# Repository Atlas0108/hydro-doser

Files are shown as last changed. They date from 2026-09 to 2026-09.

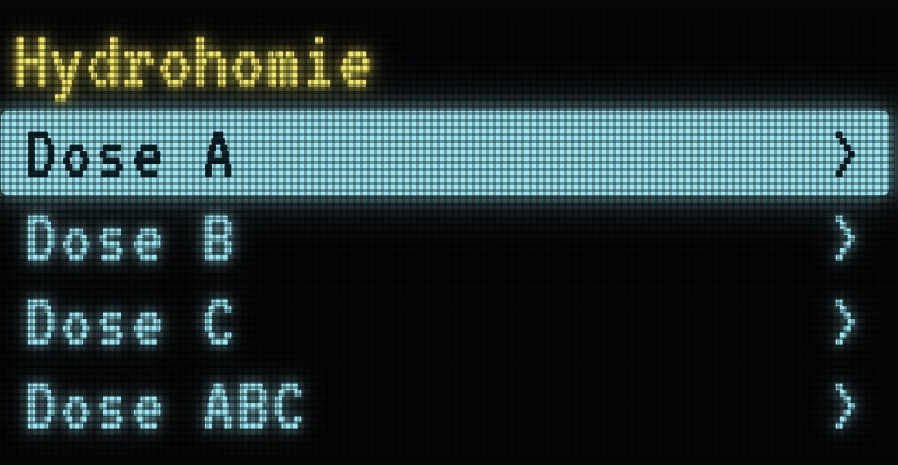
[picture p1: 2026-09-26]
v3/render/screen.jpg

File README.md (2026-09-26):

# Hydro Doser

> **v3 is in [`v3/`](v3/)**: a clean-sheet enclosure on its own feet, a faceplate
> with a screen, a knob and the ESP32, snap-on lid, the pumps across the back.
> Its firmware is in [`firmware/v3/`](firmware/v3/). What follows is v1.

## v3

See [`v3/README.md`](v3/README.md) and [`v3/BRIEF.md`](v3/BRIEF.md).

A low unit that stands beside a hydroponic garden and doses straight into it:
a water tank for top-offs, the Nutrient A and Nutrient B bottles, and three
peristaltic pumps. The firmware is in `firmware/` (still the
earlier four-pump, mix-tank version; it waits until the hardware is
settled).

**Status: printable design, not yet printed.** Seven printed pieces, all
inside the P1S bed, bolted together, no glue, no supports, no special
fittings: the tank is a stock Cambro bin with one hole drilled in its lid.
Layout, fit, joints, tool access and printability are checked by
`verify.sh` (58 checks). Some bought-part sizes are estimates: see *Before
printing*. This version follows an independent review, kept in
`REVIEW-2026-09-23.md`.

```
   ╭──────────╮ ╭───╮       tank: a Cambro 6 qt bin on its dock. Its line
   │  WATER   │ │Spr│       comes out of the column, in through a hole in
   │          │ │   │       the lid, and sits on the bottom
   │          │ │Thr│       column: two cans, one bottle each, front / back
   ├──────────┴─┴───┤
   │ [W]  [S]  ●○○ [T]      base: two trays bolted side by side. Pumps behind
   └────────────────┘       removable covers; one sleeved bundle leaves the
   345 × 225 × 315 mm       back, to the reservoir
```

## Why this shape

- **No mix tank.** A hydroponic reservoir circulates its own water, and the usual
  instruction is to add concentrate to it with each top-off. Dosing
  into the reservoir directly removes a tank, a pump, a manifold, and the
  siphon and stratification problems the review found in the mix tank.
- **Every outlet ends in air.** The three lines run to a printed spout that
  hangs on the reservoir's rim and holds the tube ends above the water.
  Only pickups sit on the bottom (in the tank and the bottles). A primed
  line can't siphon in either direction, and a dose leaves the line after
  every run instead of sitting in it.
- **Nutrient A and Nutrient B never share a line.** Two-part concentrates
  precipitate when they meet undiluted, so each has its own pump, chase,
  and outlet.
- **The tank is a stock Cambro bin with a drilled lid.** Its line comes out
  of the top of its chase, 40 mm above the lid, crosses 30 mm, drops through
  a 10 mm hole and sits on the bottom. To fill: lift the lid, or lift the bin out
  from under its tube. A 3 mm curb on the plate locates it; a 1.5 mm rim
  keeps spills on the plate and a notch at the back drains them off the
  outside of the case.
- **Nothing electrical under the tank.** The ESP32, the ULN2003 and the
  buck sit on standoffs in the column tray, behind the Nutrient B pump.
- **Pumps are serviceable without lifting anything.** Each pump drops into
  its tray from above, motor through a U-slot in a bulkhead, head in the
  front bay behind a 50 mm opening. Its two flange screws are driven from
  the front through that opening; a cover with four countersunk screws
  closes it. The INTLLAB pump's tube nozzles stand off the top of its head,
  so each pump is rolled 42° about its axis: the nozzles point up and
  sideways into the room beside the head, 4.6 mm under the plate, and both
  mounting holes (48.5 mm apart on the flange's axis) land on solid
  bulkhead, clear of the slot. The tubes loop back through a 12 × 28 mm
  slot in the bulkhead.
- **The column is two cans.** The pockets are the walls, so there's no box
  around them, no bridging, and about half the plastic of a boxed column.
  Two walls run from can to can and fuse into both, making the pair one
  box section; the left one carries the tank chase. Three chase tubes, as
  tall as the walls, carry the lines: Nutrient A's and Nutrient B's from the bottle
  caps down through the floor, the tank line up from the floor and out of
  the top. The column's floor
  plate screws down at the three corners the cans leave exposed,
  countersunk, reachable from above.
- **Two trays make the base**, sliced from one rounded body so the seam has
  no groove: three M3 through-bolts (one high, at the middle, so the trays
  can't hinge), three 14 mm tube holes, a wire hole. The bulkhead runs to
  the plate and a second crossbar sits under it, so the 4 mm plate has
  three supports under the tank.

## Pieces

`./export.sh` writes each one into `stl/`, as it prints: standing, no
supports. Masses are solid PETG; the slicer's infill brings the plate and
floors down. Three colours: the trays, plate and the column's floor in matte olive, the
column's towers and the spout in matte white, the sleeves and pump covers in
matte black. For the column, load `stl/two-colour/column_floor.stl` and
`column_towers.stl` together as one object with several parts (Bambu Studio
asks) and give each its filament; they are already in position.

| Piece | Print | Size (mm) | ~g | |
|---|---|---|---|---|
| `tray_dock` | 1 | 225 × 225 × 66 | 580 | tank dock, Water + Nutrient A pumps, panel |
| `tray_col` | 1 | 120 × 225 × 66 | 335 | Nutrient B pump, electronics, jacks |
| `plate` | 1 | 225 × 225 × 7 | 270 | dock plate: curb, drip rim |
| `column` | 1 | 120 × 225 × 249 | 870 | two cans, web walls, three chases; in two colours as `stl/two-colour/column_floor.stl` (green) + `column_towers.stl` (white) |
| `sleeve` | 2 | 95 × 95 × 243 | 180 | for the 125 mL bottles; skip for 1 L |
| `cover` | 3 | 68 × 62 × 2 | 11 | pump covers, 5 mm around each screw |
| `spout` | 1 | 40 × 20 × 42 | 19 | hangs on the reservoir's rim |
| `panel_plate` | 1 | 36 × 48 × 12 | 17 | behind the front wall: two 6 × 6 tactile switches, the LED in its bezel tube |
| `button_cap` | 2 | 14 × 14 × 6 | 1 | through the 12.5 holes, flange behind |

**PETG**, 3 walls, 15 % infill, brim on the big flat pieces. Every piece's
bed contact and unsupported area are measured by `verify.sh` (45° cones
pass, flatter overhangs don't).

Hardware: 9 × M3 heat-set inserts (4 dock posts, 3 column posts, 2 in the
panel plate), 7 × M3×8 countersunk (plate, column), 6 × M3×8 countersunk
(covers), 2 × M3×8 countersunk (panel plate, from the front), 6 × M3
self-tapping (pump flanges), 3 × M3×12 with nuts (seam), M2.5 for the
boards.

**The panel.** Drop the two switches into the plate's pockets (pins out the
back), push the LED in from the back until its flange meets the shoulder,
set the caps in their recesses, offer the plate up behind the wall so the
caps and the LED tube come through, and put in the two screws from the
front. The switch plunger sits 0.1 mm behind the cap; the cap bottoms after
0.4 mm, past the switch's click. Solder the leads on the back afterwards.

## Bill of materials

Everything that isn't printed, with two places to buy each. Roughly
$230 for the parts and $75 for the filament.

| | Qty | Source | Amazon |
|---|---|---|---|
| Cambro CamSquare 6 qt container, translucent (6SFSPP190) | 1 | [WebstaurantStore](https://www.webstaurantstore.com/cambro-6sfspp190-6-qt-translucent-square-food-storage-container-with-winter-rose-colored-gradations/2146SFSPP.html) | [Amazon](https://www.amazon.com/dp/B07FC7L861) |
| Cambro seal lid for the 6 and 8 qt (SFC6SCPP190), drilled Ø10 | 1 | [WebstaurantStore](https://www.webstaurantstore.com/cambro-sfc6scpp190-translucent-6-and-8-qt-camwear-seal-cover/214SFC6SCPP.html) | [Amazon](https://www.amazon.com/dp/B01L7RKD9W) |
| INTLLAB 12 V peristaltic dosing pump, 3 × 5 mm tube (Amazon sells a 4-pack) | 3 | [INTLLAB](https://intllab.net/products/mini-12v-peristaltic-dosing-pump) | [Amazon](https://www.amazon.com/dp/B088TBKNSY) |
| Silicone pump tubing, 3 mm ID × 5 mm OD, about 6 m | 1 | [INTLLAB](https://intllab.net/products/peristaltic-doing-pump-tubing) | [Amazon](https://www.amazon.com/dp/B092V7B77V) |
| ESP32-DevKitC, 38 pin (Amazon's is the WROVER-E variant, same footprint) | 1 | [DigiKey](https://www.digikey.com/en/products/detail/espressif-systems/ESP32-DEVKITC-32E/12091810) | [Amazon](https://www.amazon.com/dp/B087TNPQCV) |
| ULN2003 driver board (six of its seven channels: two per pump) | 1 | [Makerfabs](https://www.makerfabs.com/uln2003-stepper-motor-driver.html) | [Amazon](https://www.amazon.com/dp/B07X2WGK2P) |
| 12 V → 5 V step-down regulator, 2 A or more (Pololu D24V22F5, or any small buck module) | 1 | [Pololu](https://www.pololu.com/product/2858) | [Amazon](https://www.amazon.com/dp/B0GYJDP96Q) |
| 12 V 2 A wall adapter, 5.5 × 2.1 mm plug, UL listed | 1 | [DigiKey](https://www.digikey.com/en/products/detail/cui-inc/SWI25-12-N-P5/7070093) | [Amazon](https://www.amazon.com/dp/B013S9RGNS) |
| Panel-mount DC jack, 5.5 × 2.1 mm, threaded | 1 | [Adafruit](https://www.adafruit.com/product/610) | [Amazon](https://www.amazon.com/dp/B07C46XMPT) |
| Resettable fuse, 1.6 A hold, radial (Bourns MF-R160) | 1 | [DigiKey](https://www.digikey.com/en/products/detail/bourns-inc/MF-R160/259972) | [Amazon](https://www.amazon.com/dp/B0DHSW186L) |
| Vertical float switch, polypropylene, with cable (Cynergy3 RSF54Y100RC) | 1 | [DigiKey](https://www.digikey.com/en/products/detail/sensata-cynergy3/RSF54Y100RC/753328) | [Amazon](https://www.amazon.com/dp/B07DYW1C7P) |
| GX12 6-pin panel connector, socket and plug (float switch, TDS probe, temperature probe) | 1 | [ZYLtech](https://www.zyltech.com/new-zyltech-aviation-plug-6-pin-12mm/) | [Amazon](https://www.amazon.com/dp/B089YT21LY) |
| 6 × 6 × 5 mm tactile switch, 4 pin | 2 | [Adafruit](https://www.adafruit.com/product/367) | [Amazon](https://www.amazon.com/dp/B0796QHL5Z) |
| 5 mm green LED | 1 | [Adafruit](https://www.adafruit.com/product/298) | [Amazon](https://www.amazon.com/dp/B01C3ZZTB4) |
| Push-in grommet for a 5/8" hole, 1/2" ID | 1 | [Grainger](https://www.grainger.com/product/GRAINGER-APPROVED-Grommet-3MPL5) | [Amazon](https://www.amazon.com/dp/B0FH2DNHN6) |
| Expandable braided sleeving, 1/2", 10 ft | 1 | [McMaster-Carr](https://www.mcmaster.com/9284K614/) | [Amazon](https://www.amazon.com/dp/B071ZV6MZ2) |
| M3 brass heat-set inserts (9 used) | 1 pack | [McMaster-Carr](https://www.mcmaster.com/94459A130/) | [Amazon](https://www.amazon.com/dp/B0BVMMBG2N) |
| M3 × 8 flat-head socket screws, stainless (15 used) | 1 pack | [Bolt Depot](https://boltdepot.com/Product-Details?product=7213) | [Amazon](https://www.amazon.com/dp/B01HBN0UU8) |
| M3 × 12 socket-head screws, stainless (3 used, the seam) | 1 pack | [Bolt Depot](https://boltdepot.com/Product-Details?product=6381) | [Amazon](https://www.amazon.com/dp/B01MYX1XBO) |
| M3 hex nuts, stainless (3 used) | 1 pack | [Bolt Depot](https://boltdepot.com/Product-Details?product=4773) | [Amazon](https://www.amazon.com/dp/B01MYX1XBO) |
| M3 × 10 thread-forming screws for plastic (6 used, the pump flanges) | 1 pack | [McMaster-Carr](https://www.mcmaster.com/95893A191/) | [Amazon](https://www.amazon.com/dp/B0779QYZXH) |
| Matte olive green PETG, 1 kg: the trays, plate and column floor | 2 | [California Filament](https://californiafilament.com/products/matte-olive-green-petg-filament-1-75mm-1kg) | [Amazon](https://www.amazon.com/dp/B0GGB1TS3Z) |
| Matte white PETG, 1 kg: the column's towers and the spout | 1 | [eSUN](https://esun3dstore.com/products/petg-matte) | [Amazon](https://www.amazon.com/dp/B0GGBCGJBC) |
| Matte black PETG, 1 kg: the sleeves and pump covers | 1 | [California Filament](https://californiafilament.com/products/matte-black-petg-filament-1-75mm) | [Amazon](https://www.amazon.com/dp/B0GGBMB1HJ) |

## Before printing

1. **Measure a Cambro 6 qt bin and lid**, a small nutrient bottle and a pump, and put
   the numbers in at the top of the `.scad` (`bin_bot`, `bin_r`, `lid_w`,
   `lid_above`, `pump_*`, `b125`). Only the bin's nominal outside size is
   from the spec sheet.
2. **Measure the reservoir's fill opening** for the spout (`rim_t`,
   `rim_drop`).
3. **Print the column tray and one cover first.** They test a pump opening,
   the U-slot, the tube slot, the cover screws, the standoffs and the jacks
   for a few dollars of filament.

**The first dock tray** was printed before the pump drawing arrived, with
the pump axis 2 mm higher (z 34) and pilot holes for a guessed bracket. It
still works: seat each pump at the bottom of its U-slot, roll it 43° so the
nozzles point up and toward the neighbouring pump, mark through the flange's
two holes, and drill Ø2.5. That clears the plate by 2.8 mm. It also has no
holes for the panel plate's screws: drill Ø3.5 at 183 mm from the dock's
left edge, 16 and 52 mm up, and countersink them from the front.

## Files

Published on its own at <https://github.com/Atlas0108/hydro-doser> (this
folder at the root, `firmware/` as `firmware/`); this copy is
the working one.

```sh
./export.sh                                   # every piece into stl/, plus mockup.stl
./verify.sh                                   # 57 checks (export first)
openscad -D 'bottles="1L"' hydro-doser.scad    # the scaled-up bottles
```

`mockup.stl` is the assembled unit with its bought parts, one body, for
viewing only. Open the `.scad` in OpenSCAD to see it in colour.

`verify.sh` checks: the tank clears everything and lifts straight up, the
curb is 3 mm and stops a misplaced tank, the rim is lower than the curb,
the lid hole is over the bin with a straight drop to the floor, the tank
line comes straight out of the top of its chase, 20+ mm above the lid, and the
chases stand as tall as the web walls; 1 L bottles
and the sleeves fit, a 125 mL bottle sits with its cap at the rim, each
chase runs clear top to tray and none opens into a pocket, each web wall fuses into both cans; the pumps sit
inside and lift straight out, the covers fit and their screws meet their
ribs, the flange screws can be driven from the front, each pump's tubes
have a 20 mm loop and pass their slot; the boards rest on standoffs, clear
everything and fit under the column; the panel hardware fits; the seam
carries its holes; the floors are closed; no two printed pieces overlap,
every screw meets its hole, a driver reaches every column and plate screw,
every post stands against a wall, the bulkhead reaches the plate; and every
exported STL fits the P1S, sits on the bed with real contact area, and has
no unsupported overhang.

## Next

- **Firmware** (on hold until the hardware is settled): three pumps, dose
  and top-off straight into the reservoir, the float gate on every run, a water
  tank counter with a refill button, a rolling daily water cap, the panel's
  buttons and light.
- **Level sensing:** a load cell under the dock plate would weigh the tank;
  the plate has the room.
- **Tube ends:** a small weight or a printed foot on each pickup keeps it on
  the bottom.
- **A product version** would mould the two trays as one, the column as one,
  with bosses instead of inserts, a moulded tank and lid, one PCB instead of
  the DevKit and driver boards, and a snap-on pump cover. The layout
  survives.

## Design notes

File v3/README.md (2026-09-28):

# Hydro Doser v3

Detailed to `BRIEF.md`. A printed enclosure on its own feet: three
peristaltic pumps, a screen, a knob and the DevKit on a black faceplate,
the driver and the buck on the side walls, and the two 125 mL nutrient
bottles standing in a deck on the lid. No tank under it.

```
   from the front                          from above, lid off
   ╭───────────────────╮                   ╭───────────────────╮
   │     [=]   (o)     │  bottles 37       │ ═══ ═══ ═══  pumps│  heads forward, rolled 42°,
   │  ▔▔▔▔▔▔▔▔▔▔▔▔▔    │  above the deck   │ ▪   (B)   (A)   ▪ │  motors to the back
   ╰───────────────────╯                   ╰───────────────────╯  ▪ wall boards, (A)(B) cups
    ▪               ▪   feet
   202 x 178 footprint, 85 tall from the plate's underside to the lid, 89 at the deck
```

The lid snaps on; the faceplate is the only screwed piece,
its four screws at the centres of its corner radii. The feet sit at the
centres of the body's corner radii. Every edge is rounded.

Published at <https://github.com/Atlas0108/hydro-doser> under `v3/`, with
the firmware under `firmware/v3/`; this copy is the working one.

## Pieces

| Piece | Prints | Size | |
|---|---|---|---|
| `body` | floor down | 202 × 178 × 82 | floor and walls in one: bulkhead, cups, wall-board ribs, vents, the front opening, the feet's pockets, the rim on top |
| `lid` + `lid_deck` | underside down | 202 × 178 × 11 | flat underneath but for its pocket; the deck on top is the second file, printed black |
| `plate` | face down | 176 × 59 × 28 | black; the screen's pocket, the knob's ribs, and standoffs for the DevKit and the TDS board on its back |
| `knob` + `knob_cap` | base down | Ø36 × 9.5 | the knurled ring brown-red, the cap (face and rounded edge) black; the D bore reaches 1.2 short of the face; the encoder's shaft is cut to 16 above its pcb |
| `ph_adapter` | the bridge's flat back down | 51 × 33 × 18 | no longer used; it clamped the encoder's rib and carried the pH board |
| `foot` | disc down, TPU | Ø18 × 6 | four |
| `spout` | top down, legs up | 40 × 16 × 34 | clips the reservoir's rim |

The lid and the knob each come as two STLs in the same place: the olive (or orange) part and its black part. Load the pair as one object in the slicer (Bambu Studio: import both together and answer yes to loading them as a single object with multiple parts), then give the black part the black filament.

`./export.sh` writes them into `stl/` as they print, no supports. The
front band slopes at 45° underneath; the vents' ceilings, the lid's
pocket ceiling is a short bridge.

Hardware: 4 × M3 heat-set inserts and 4 × M3 × 8 countersunk (the
faceplate), 6 × M3 × 8 (pump flanges, from the motor side, threading into
the flanges' Ø3.2 holes). Bought parts as in `BRIEF.md`.

## How it goes together

- **Body.** Floor and walls in one piece, open at the top. The floor is
  4 thick with a 1.5 chamfer under its edge, the one edge that is not
  rounded, because it prints from the bed. Four TPU feet snap into the
  floor at the corners' radius centres, a disc in a pocket underneath and
  a lipped peg into a counterbore above, flush with the floor's top.
- **Pumps.** Three INTLLAB pumps lie across the back, heads forward,
  motors through U-slots in a bulkhead at 125 and back to the wall, all
  standing on the floor. Each
  is rolled 42° about its axis, as in the first design, so its diamond
  flange's two holes sit on a 42° line: one high on the right, one low on
  the left of the axis. The bulkhead has Ø3.4 holes to match; the screws
  go in from the motor side, between the motors with a stubby or
  right-angle driver, and thread into the flange. Nozzles lean left. Pump
  0 (right) is Nutrient A, pump 1 (middle) Water, pump 2 (left) Nutrient
  B.
- **Cups.** Two Ø52 tubes (2 mm round the Ø48 bottles) side by side in the middle of the front, open
  at both ends. A bottle stands on the base plate and shows 37 above the
  deck. Two Ø8 holes through the lid, their mouths rounded, one 16 out
  from each bottle on its outer side for the nutrient tube. The water
  tube comes in through a plain Ø8 hole high in the back wall, above
  the middle motor, and runs forward over the motor and the bulkhead to
  the nozzles.
- **Bottles.** The Rise Gardens 125 mL Sprout and Thrive bottles, measured
  Ø48 × 122: a white HDPE cylinder round, rounded shoulder, 24 mm neck, a
  black disc-top cap, a wraparound label (Sprout green, Thrive blue). In the
  model as body, cap and label so the pages and the render colour them apart.
- **Wall boards.** The ULN2003 stands in two slotted ribs on the right
  wall and the buck in two on the left, beside the cups, dropped in from
  above with the lid off; the boards rest on the slots' floors just off
  the body's floor, components inward.
- **Vents.** Seven rounded slots, 40 × 2, in each side wall beside the
  motors, at 5 mm pitch from 12 up.
- **Faceplate.** A black plate, 3 thick, 96 × 59, centred on the front
  and flush with it, its edge and the opening's edge rounded 1 so the
  seam is a soft groove. Four M3 × 8 at its corner-radius centres into
  inserts in a 12 mm band behind the wall. On its back: the OLED drops
  straight into a pocket, a 3 mm frame 0.3 clear each side and 0.2 top
  and bottom, its glass in a blind recess behind the face (a dab of hot
  glue or foam tape keeps it seated); the window
  the size of its picture; the KY-040 sits between two ribs, its nut on
  the floor of a Ø38 × 2 recess, and the Ø36 knob hides the nut in a
  pocket in its base, sits 0.5 off the recess floor, and stops on the
  shaft's end (the KY-040's 20 mm shaft cut to 16 above the pcb; the
  knob is 9.5 thick and its D bore runs to 1.2 short of the face).
  The screen sits dead centre; the knob is midway between the screen's
  centre and the plate's right edge. Left of the screen, as seen from
  the front, the 30-pin ESP32 DevKit lies along the plate, its left end
  4 short of the left screws' inserts. It stands on four Ø5.5 standoffs, 5 tall, module toward the plate and
  pins pointing into the box, held by M2.5 self-tappers through its
  corner holes into Ø2.2 pilots. The holes are taken as Ø3, 2.3 in from
  each edge (46.9 × 23.7 apart): measure your board and change
  `esp_hole` if it differs. The band behind the wall is notched there
  so the board clears it, the notch's ceiling sloped 45° so it prints.
  Straight behind the screen, the DFRobot Gravity TDS (or pH V2) signal
  board, 42 × 32, lies along the plate on four Ø6 standoffs, 25 tall, so
  it clears the screen's header and the Dupont plugs on it; its back
  runs between the two cups. Two of the standoffs merge into the
  screen's side ribs. M3 self-tappers through its corner holes into
  Ø2.6 pilots. The holes are taken as Ø3.1, 3.5 in from each edge (35 ×
  25 apart): measure your board and change `tds_hole` if it differs.
  Fit the screen before the board: the board covers its way in.
  The knob's encoder is fitted with its pins out of its short edge,
  toward the plate's right edge, so only one rib stands beside it (the
  one toward the screen); its harness leaves past the open side. It
  stands 14 off the plate's back. (No longer used: the pH probe now
  keeps its own cable through the back wall, and the pH board is off the
  faceplate. Skip printing `ph_adapter`.) The pH board (PH-4502C type, 42 × 32)
  hung on that rib on a printed adapter, `ph_adapter`:
  a leg on the rib's outer face, a lip over its top, and a tab on its
  inner face above the encoder's board clamp it both ways; a bridge 1.5
  behind the encoder reaches across the harness side and carries the
  board flat on its back, toward the harness side so its parts clear
  the right cup, and rests on a second full-height leg at its far end,
  windowed for the harness. M3 self-tappers into Ø2.6 holes through the
  bridge. The holes are
  taken as Ø3.1, 3.5 in from each edge (35 × 25 apart): measure yours
  and change `phb_hole` if it differs.
  Fit all four, then screw the plate on.
  The window sits 14 from the plate's edge, the same as the knob's
  recess; the screen's outer rib lands where the band would be, so the
  band is notched there between the two screws.
- **Back.** The jack, the pH cable's hole and the GX12-6 on one line
  low in the back wall, 11 up from the floor's top: the jack and the
  GX12 between the motors, the pH hole (Ø16) under the middle motor.
  The pH probe keeps its stock cable: its BNC plug (about 14.5 across)
  passes through, and a grommet goes back round the cable. Above the
  middle motor, 48 up, three Ø6.4 holes 13 apart take the outlets'
  uxcell M6 bulkhead barbs (B0F5X3DXQ5): 3 mm barb outside for the
  hoses, nut and 4 mm barb inside for the doser's tubes. They sit right
  of centre so a driver still reaches the middle pump's upper screw.
  The nutrient tubes run back over the bulkhead and down to them. The
  water tube's hole is above them, 58 up.
- **Lid.** Flush with the walls, 7 thick with a 4 mm round on its edge.
  A 1.5 mm rim rises 4 from the walls' inner half with a ridge round its
  inside; the lid's underside has a pocket ring over it with a groove the
  ridge clicks into, so nothing hangs below the lid and it prints flat.
  A raised deck over the cups, rounded on top with a cove at its foot.

## Texture

The body's vertical faces get a fuzzy-skin band, from 4 above the bottom
up to the lid seam, so it clears the faceplate by the same 3.3 above and
below, stopping 3 mm short of the faceplate's
opening. The faceplate, lid and base stay smooth. It is a slicer effect,
so nothing in the STL changes; `stl/fuzz-modifier.stl` is a modifier
shell that puts it exactly there:

1. In Bambu Studio or OrcaSlicer, select the body, right-click, Add
   Modifier, Load, pick `fuzz-modifier.stl`. It lands in place (same
   origin as `body.stl`).
2. On the modifier, set Fuzzy Skin to Contour, thickness 0.3, point
   distance 0.8. In OrcaSlicer 2.3 or later pick a noise type: Perlin at
   feature size 1 for a fine grain, Voronoi at 2 to 3 for a patchwork.
3. Leave Fuzzy Skin off on the body itself and every other piece.

Contour fuzzes only the outer wall, and only inside the shell, so the
snap fits, the opening and the cavity stay smooth. Print a small test
band first: fuzzy skin adds 0.3 to the outside, so the lid and base seams
show a 0.3 step unless the texture band is what you want to read there.
(The body's bottom 4 mm and the lid sit inside the band.)

## Checks

`./verify.sh` (export first) runs the boolean checks: the floor closed;
feet at the radius centres, snapping in and staying under; the
lid on the shoulder, its pocket over the rim, snapping, located, flush,
flat underneath; bottles dropping in and showing 30; tubes up through
their three holes; pumps seated, lifting out, their flange screws on the
42° line reaching from the back with a driver; tube runs to the holes
and the grommet; the DevKit on its standoffs, the wall boards in their
slots, all sliding in, held and clear; ports between the motors; vents
open; the plate seated on its band, flush, held every way, its screws
at its radius centres, the seam groove open; the encoder, nut, knob and
D flat; the screen sliding in, held, its picture shown; the spout; every
piece on the bed, unsupported and manifold.

## Open

- The bottles measure Ø48; their height, 122, is still an estimate.
- Firmware: v1's pin plan with the pumps re-labelled (0 A, 1 Water, 2 B),
  the OLED on GPIO21/22, the encoder on 18/19/23.
- The float switch has no mount yet.

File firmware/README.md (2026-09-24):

# Hydro Doser → mixes nutrient water and tops off the garden

An ESP32 running ESPHome (`hydro-doser.yaml`), with four 12 V peristaltic
pumps (INTLLAB 4-pack) switched by two ULN2003 boards.

**Status: firmware written and compiling. Hardware not built yet.**

```
 Nutrient A bottle ──[Nutrient A]──┐
 Nutrient B bottle ──[Nutrient B]──┤
 water jug     ──[Water]───┴──►  mix tank  ──[Transfer]──►  reservoir
                                                              (float switch)
```

The reservoir only ever gets something from the mix tank: plain water
(*Mix Water Batch*) or nutrient water (*Mix Nutrient Batch*). Nutrient never
goes straight into the garden, and Nutrient A and Nutrient B never touch each other
undiluted.

## Parts

| | |
|---|---|
| ESP32 dev board | any ESP32-WROOM DevKit (`board: esp32dev`) |
| 4 × peristaltic pump | INTLLAB 12 V DC, 5–100 mL/min. The motor must stay dry: mount the pumps above the tanks. |
| 2 × ULN2003 board | the ones from the stepper kits, jumper set to 5–12 V |
| 12 V supply | 12 V, 2 A or more |
| 12 V → 5 V buck | powers the ESP32 from the same supply |
| Float switch | in the reservoir, at the fill line |
| Mix tank | anything with a lid. Set *Mix Tank Capacity* to match. |
| Silicone tubing | to fit the pump barbs, plus spares: pump tubing wears out |

## Wiring

| ESP32 | goes to | |
|---|---|---|
| GPIO25 | board A IN1 **and** IN2 | Nutrient A |
| GPIO26 | board A IN3 **and** IN4 | Nutrient B |
| GPIO27 | board B IN1 **and** IN2 | Water |
| GPIO32 | board B IN3 **and** IN4 | Transfer |
| GPIO33 | float switch → GND | reservoir full |
| GND | both boards' −, buck −, 12 V − | **common ground, required** |
| VIN (5V) | buck 5 V out | |

Each pump uses two channels in parallel, so there's plenty of current margin.
On each board, the pump's **+** goes to the board's **+** pin (12 V). Its
**−** goes to both OUT pins on the white connector for its two channels.
The ULN2003 has flyback diodes built in. If the ESP32 resets when a pump
starts, solder a 100 nF capacitor across that motor's terminals.

**The float switch has to be fail-safe.** Mount it so the contact is **closed
while the water is below it**. Most float switches flip over to change which
way they work. An open circuit reads *full*: an unplugged or broken switch
blocks transfers rather than letting the pump run until the reservoir
overflows. With no float wired, *Transfer to Reservoir* does nothing, by design.

## Calibrate before first use

The pumps are rated "up to 100 mL/min". The real rate depends on the tubing
and on the ~1 V the ULN2003 drops, so measure it:

1. Put the pump's inlet in its liquid and its outlet in a measuring cup.
2. Choose it in *Calibrate Pump*, then press *Run Pump 60 s*. The first run
   also primes the tube, so empty the cup and run it a second time.
3. Enter the mL it moved as that pump's *Flow* (mL/min).

Recalibrate every few months. As the tubing wears, the flow drops.

## Use

1. Set **Nutrient A Dose** and **Nutrient B Dose** (mL per liter of water) from the nutrient maker's
   feeding directions. Both start at 0. Set Nutrient A back to 0 once the plants
   no longer need it.
2. **Mix Nutrient Batch** or **Mix Water Batch** fills the mix tank with
   *Batch Size* liters: 80% of the water, then Nutrient A, then Nutrient B, then the
   last 20% of the water to rinse the lines and stir the tank. The whole batch
   is checked first: if it won't fit in the tank or needs too long a run, it
   doesn't start.
3. **Transfer to Reservoir** pumps up to *Transfer Amount* liters (0 means all of
   it) into the garden. It stops early if the float trips or the mix tank
   runs out.
4. **Stop** stops everything. A run that was cut short still counts toward the
   mix tank.

**Status** shows the last thing the doser did or refused. **Nutrient A Used** and
**Nutrient B Used** count up from the last *Bottle Refilled* press.

The same things are available as HA actions, for automations:
`esphome.hydro_doser_dose` (`pump`: sprout/thrive/water/transfer, `ml`),
`esphome.hydro_doser_make_batch` (`liters`, `nutrients`),
`esphome.hydro_doser_transfer` (`liters`, 0 = all).

## How it keeps count, and its limits

Nothing measures the mix tank. **Mix Tank Volume** is flow rate × run time,
kept across reboots. If it drifts (spills, hand-filling, a bad calibration),
empty the tank and press *Mix Tank Emptied*.

- Only one pump runs at a time. Commands wait in a queue.
- A single run is capped at 45 min (4.5 L at 100 mL/min). A fill needing more
  than that is refused; a transfer stops at the cap and leaves the rest.
- A dry water jug isn't detected. Peristaltic pumps survive running dry, but
  the count will then overstate what's in the tank.
- At ~100 mL/min, a 2 L batch takes about 20 min, and so does the transfer.

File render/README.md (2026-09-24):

# Renders and pages

Source for the exploded-view page, the product page and the Blender
explosion. Frames, part STLs for the viewer and the MP4 are outputs and are
not kept here; regenerate them.

| File | What |
|---|---|
| `doser.py` | Blender 5.2 scene: imports the part STLs (each bought part as its own pieces), matte olive PETG, a dark studio, animated screws, and renders the explosion as a 96-frame WebP sequence plus a hero still. `--device CPU\|METAL\|HIP`, `--test` renders four check frames. |
| `encode.py` | Blender's FFmpeg: frames → MP4, forward, hold, reverse, hold. |
| `viewer.html` | The interactive exploded view (three.js). Expects `parts/<name>.txt`: base64 binary STLs, one per part instance. |
| `product.html` | The product page. Expects `frames/f001..f096.webp` and `frames/hero.webp`. |

```sh
# part STLs for the viewer / Blender, one per instance (see the scad's output section)
openscad -o parts/column.stl --export-format=binstl -D 'part="piece"' -D 'idx=3' ../hydro-doser.scad
# full render on node-01 (32-thread CPU, ~40 s a frame at 64 samples)
blender -b -P doser.py -- --device CPU --frames 96 --samples 64 --parts parts --out frames
blender -b -P encode.py -- frames hydro-doser-explosion.mp4
```

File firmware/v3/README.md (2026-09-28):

# Hydro Doser v3 firmware

ESPHome on an ESP32 DevKitC. A 0.96" OLED and a KY-040 knob on the
faceplate drive a menu, so it works without a phone: turn to choose, click
to open, click to run, turn up past the top to go back. Three 12 V peristaltic pumps
through a ULN2003. Home Assistant sees it as a device with three pump
switches, a Cancel button, a Status text, a flow-rate number per pump, and
`dose` and `cancel` actions. Whatever Home Assistant starts shows on the
screen the same as a knob-started run: the countdown and the cancel
button, or the manual page with a stop button.

## Setting it up

Nothing is baked in: no network, no password, no key. Plug it in and
set it up on a network. Two ways,
both local:

1. Open the Home Assistant app on a phone near it, with Bluetooth
   allowed. It finds "hydro-doser-v3" over Bluetooth (Improv) and asks
   for the Wi-Fi network and password. Any Improv client works the same
   way; the unit here was set up from a Mac with a 40-line Python script.
2. Or join the open Wi-Fi network "Hydrohomie" the doser raises; a page
   pops up to enter the network and password.

Once it is on the network it remembers it, and Home Assistant lists it
under Discovered on the integrations page; click Add. No key to paste.
If Home Assistant runs in Docker on a Mac with port mapping, as on the
iMac here, it cannot see mDNS and will not discover anything: add the
ESPHome integration by hand with the host `hydro-doser-v3.local` (or its
address) and port 6053. To make a unit forget its network, erase the
`nvs` partition (`esptool erase_region 0x390000 0x70000`) or hold no
network: the set-up modes come back.

A dose's time is ml divided by the pump's flow rate. The rates default to
100 mL/min; calibrate each pump (run 50 ml into a measuring cup, adjust
the number in Home Assistant) before trusting the quantities.

## Wiring

Everything on the faceplate's back. The OLED's four pins face into the
box; the knob's five pins point down.

| From | To ESP32 | Notes |
|---|---|---|
| OLED GND | GND | |
| OLED VCC | 3V3 | the 0.96" SSD1306 boards run on 3.3 V |
| OLED SCL | GPIO22 | I2C clock |
| OLED SDA | GPIO21 | I2C data |
| Knob CLK | GPIO19 (D19) | encoder |
| Knob DT | GPIO18 (D18) | encoder |
| Knob SW | GPIO5 (D5) | the push button, pulled up in firmware |
| Knob + | GPIO17 (TX2) | driven high at boot: its 3.3 V |
| Knob GND | GPIO16 (RX2) | driven low: its ground |

The knob's five pins, CLK, DT, SW, + and GND, land on D19, D18, D5, TX2
and RX2, which sit side by side on the DevKit V1's header, so its plug
goes on in one piece with CLK on D19. The two pins at the end power it;
it draws about 1 mA. If it turns the wrong way, swap `pin_a` and
`pin_b` in the yaml. The OLED's address is 0x3C; if the screen stays dark
and the log says no device at 0x3C, it is the 0x3D kind: change `address`.

Pumps, through the ULN2003 (its + and its jumper as in the first
design). The menu's A, B, C are Nutrient A, Nutrient B, Water:

| From | To ESP32 | Menu |
|---|---|---|
| ULN2003 IN1 | GPIO25 | A, Nutrient A, the right pump |
| ULN2003 IN2 | GPIO26 | C, Water, the middle pump |
| ULN2003 IN3 | GPIO27 | B, Nutrient B, the left pump |
| ULN2003 - | GND | |

The Gravity TDS (or pH V2) signal board, on its 3-pin plug. Its supply
comes from GPIO13, so the firmware can switch the board off while pH
reads (it draws a few mA). GPIO35 is on ADC1, which reads with Wi-Fi
on.

GPIO32, the board's first supply pin, was damaged on 2026-09-28. The +
and - wires moved to D13 and the GND pin beside 3V3, and GPIO32 and GPIO33
are left unused. Before powering the board from a new pin, check its +
and - aren't shorted together (unplugged, the meter should read well
over 1 kΩ between them), or the new pin goes the same way.

| TDS board | To ESP32 | Notes |
|---|---|---|
| A (signal) | GPIO35 | analog in, 0 to 2.3 V |
| + | GPIO13 | driven high at boot: 3.3 V |
| - | GND | the GND pin beside 3V3, bottom of the other side |

On the 30-pin DevKit V1, D13 is near the bottom of the VN-side header
(... D14, D12, **D13**, GND, VIN) and the A wire goes to D35 higher up
the same side. The - wire goes to the GND pin at the bottom of the
other side, beside 3V3: the GND beside D13 left the board unlit when
tried on 2026-09-28.

The pH board (the common PH-4502C type, 42 × 32, the one sold with a BNC
probe) needs 5 V, and its Po output reaches about 5 V at the acid end:
too much for an ESP32 input. So Po goes through a divider, 10 kΩ from Po
to GPIO34 and 20 kΩ from GPIO34 to ground, which scales 5 V to 3.3 V;
the firmware multiplies back by 1.5.

| pH board | To | Notes |
|---|---|---|
| Po | 10 kΩ, then GPIO34 | 20 kΩ from GPIO34 to GND |
| V+ | 5 V (VIN, or the buck's OUT+) | |
| G | GND | either G |
| Do, To | — | unused |

The float switch goes between GPIO14 and GND; the firmware pulls GPIO14
up. **Mount it so its contact is closed while the water is up at the
float** (flip the float on its stem to change which way it works). Then
an open contact, from low water or a broken or unplugged lead, reads
**Reservoir low**, so dosing can be blocked on it safely.

The TDS probe and the float come in through the GX12-6 in the back
wall. Cut the TDS probe's plug off and wire the board's probe input to
the GX12 socket instead:

| GX12 pin | Wire | Goes to |
|---|---|---|
| 1 | green | float switch: GPIO14 (D14) |
| 2 | yellow | TDS board's probe input (either way round with pin 4) |
| 3 | white | spare |
| 4 | blue | TDS board's probe input |
| 5 | no wire | unused |
| 6 | black | float switch: GND |

Pin numbers are as seen on the connector's front (mating face), key at
the top: pin 1 at the bottom right, 2 to 5 running anticlockwise round
the ring, 6 in the centre. The map follows the wiring as built
(2026-09-27): pin 5 has no wire. The TDS probe is on yellow and blue (2 and 4),
the float on green and black (1 and 6). The float switch has no
polarity; black takes ground by convention.

The pH probe keeps its stock cable, uncut. It comes in through its own
hole in the back wall, beside the GX12, and its BNC plugs straight into
the pH board. The pH board is no longer on the faceplate; keep it and
the cable away from the pump wires, since the probe's signal is very
high impedance.

The probes share the reservoir, and the TDS board's excitation current
upsets the pH probe. So the doser reads them in turn, every 30 s: TDS
first, then it switches the TDS board off (it is powered from two GPIOs
for exactly this), waits 3 s, reads pH, and switches the TDS board back
on to settle before its next reading. Both readings update every 30 s.

pH is two-point calibrated. Put the probe in pH 7 buffer and press
**Calibrate pH 7**; rinse it, put it in pH 4 buffer and press
**Calibrate pH 4**; each button takes a fresh reading, with the TDS
board off, before it saves. The two settings, pH 7 voltage and pH slope, can
also be set by hand.

Home Assistant gets TDS in ppm, the raw TDS voltage (diagnostic), and
two settings: Water temperature, which the reading is compensated to
25 °C with (there is no temperature probe yet, so set it), and TDS
calibration, a factor to trim the reading against a known solution.
The conversion is DFRobot's: the voltage over 1 + 0.02 × (T - 25), then
(133.42 v³ - 255.86 v² + 857.39 v) × 0.5 × the factor.

**Nutrient level** reads Low, Nominal or High against a reading marked
as nominal: the Rise reservoir dosed to spec read 592 ppm on
2026-09-26, and that is the default. It goes Low below nominal minus
the **TDS band** (10 % by default) and High above nominal plus it, with
2 % of hysteresis so it doesn't flicker at the edge. After a fresh fill
dosed to spec, press **Mark TDS nominal** to take the current reading
as the new nominal. When the probe reads 0 (dry or unplugged) the level
is "No reading", so an auto-doser built on it never doses on a dead
probe.

## Flashing

```sh
esphome run hydro-doser-v3.yaml --device /dev/cu.usbserial-110    # over USB (the CH340 port on this Mac)
esphome run hydro-doser-v3.yaml --device hydro-doser-v3.local     # over the air after that
esphome logs hydro-doser-v3.yaml --device /dev/cu.usbserial-110   # watch it
```

There is no `secrets.yaml`: the firmware has no secrets.

## In a dashboard

`dashboard-section.yaml` is a ready-made section for a Home Assistant
sections dashboard: Status, Cancel, the dose buttons at 5, 10, 25 and
50 ml for A, B, C and ABC, the manual pump switches and the flow rates.

## The menu

Home lists Dose A, Dose B, Dose C, Dose ABC and Settings.

```
  Hydrohomie  click ->   Dose A        click ->   Dose A, 25 ml
  > Dose A               > 5 ml                   12 s left
    B                      10 ml                  click to cancel
    C                      25 ml
    ABC                    50 ml
                           Manual       hold ->   A running
                                                  release to stop
```

Settings holds PIN, Autolock and Reset. PIN sets a four-digit PIN: turn
to pick each digit, click to move on; 0000 clears it. Autolock (Off,
1 min, 5 min) locks the screen after that long without a touch, and needs
a PIN first: chosen without one it says "Set a PIN first". A locked
screen asks for the PIN before the menu is usable; Home Assistant is not
affected. Reset, after a confirmation, forgets the network, the PIN and
the settings and reboots into set-up.

Turn: move the highlight. Click: open the dose, then run the quantity,
and while it runs, click again to cancel; a run started from Home
Assistant shows the same pages and a click stops it too. To go
back from any menu, turn up past the first item to highlight the title
band as Go back and click it; on PIN entry, turn back past 0 on the
first digit. Holding the button never goes back. On Manual, the pump
runs from the moment the button goes down until it is released; on
ABC's Manual all three run together. On the home screen, a 3 s hold
turns the screen off; a click turns it back on and does nothing else,
and the knob does nothing while it is off. The doser keeps working with
the screen off, and a dose started from Home Assistant turns it back on
to show the countdown, then off again when the run ends or is cancelled
(unless the knob was touched meanwhile). A hold anywhere else does nothing. A timed ABC runs A,
then B, then C, each for the chosen quantity.

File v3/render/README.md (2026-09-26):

# Render

The Blender explosion of v3. Frames, the part STLs and the MP4 are
outputs and are not kept here; regenerate them.

| File | What |
|---|---|
| `doser-v3.py` | Blender 5.2 scene: imports the parts exported in assembly position, matte olive PETG, a black plate, the brown-red knob, a dark studio, and renders a basic explosion (every part slides straight out, together, the wall boards staying put) as a 96-frame WebP sequence plus a hero still. `--device CPU\|METAL\|HIP`, `--test` renders three check frames. |
| `routes.py` | The tubes and the faceplate's heat-set inserts as routes in model mm, each point riding with the part it is attached to; `python3 routes.py > routes.json`. The scene and the exploded-view page both read `routes.json`. |
| `encode.py` | Blender's FFmpeg: frames to MP4, forward, hold, reverse, hold, 24 fps. |

```sh
# the parts, one STL each in assembly position
for p in body_at:body lid_at:lid deck:deck plate_at:plate knob_at:knob cap:cap feet:feet screws:screws encoder:encoder oled:oled ports:ports; do
  openscad -o parts/${p#*:}.stl --export-format binstl -D "part=\"${p%:*}\"" ../hydro-doser-v3.scad; done
for i in 0 1 2; do for p in pump board; do openscad -o parts/$p$i.stl --export-format binstl -D "part=\"$p\"" -D "idx=$i" ../hydro-doser-v3.scad; done; done
for i in 0 1; do openscad -o parts/bottle$i.stl --export-format binstl -D 'part="bottle"' -D "idx=$i" ../hydro-doser-v3.scad; done
# on node-01 (32 threads): a preview at about 8 s a frame, the high-quality pass at about a minute a frame
python3 routes.py > parts/routes.json
blender -b -P doser-v3.py -- --device CPU --frames 96 --samples 64 --parts parts --out frames
blender -b -P doser-v3.py -- --device CPU --frames 120 --samples 192 --width 2400 --parts parts --out frames
blender -b -P encode.py -- frames hydro-doser-v3-explosion.mp4
```

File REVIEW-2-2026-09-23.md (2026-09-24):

# Rise Doser review 2 (2026-09-23, post-rebuild)

Second independent review, of the one-tank three-pump rebuild, by a reviewer
with no part in the design and the first review in hand. Kept here because
the next round of changes is driven by it. Nothing in it has been acted on
yet.

Files: `rise-doser.scad`, `README.md`, `verify.sh`, `REVIEW-2026-09-23.md`,
`stl/*`. The reviewer ran `verify.sh` (51/51 pass), rendered the assembly
and each piece, ran 25 extra boolean probes and a per-z-band overhang
analysis.

## Previous review: what was actually resolved

Resolved: column prints on its floor (bed 26,606 mm², 65 mm² unsupported);
rails gone; column screws countersunk, outside the cans, driver-reachable;
bulkhead to 65.5 + crossbar under the plate; 3 mm curb; 10×10 posts; third
seam bolt at z=56; bottom fillet 1.5; floor slots gone; tee gone, separate
Sprout/Thrive lines; exit 45 mm above the lid (was 8.7); barb-to-slot bend
~22 mm (was 9); electronics out from under the tank; pumps front-serviceable;
standoffs exist; wire hole; button pitch 24; mix tank dropped; polyfuse in
BOM; brim documented.

**Not resolved or mis-resolved:** (a) the siphon blocker was fixed only in
the reverse direction (see §3); (b) mass target <1.5 kg: still 2,516 g solid
(`verify.sh` sum); (c) USB reach got worse (16 mm, was 6); (d) standoffs have
no screw holes; (e) round holes still not teardropped (the helper was
deleted); (f) sleeve/pocket fit 0.75 mm radial (asked ≥1); (g) bolt
heads/nuts still unmodelled; (h) tube routes still tested as stubs/boxes,
not paths; (i) no prime/flush/panel firmware (on hold, fine, but the
hardware now needs: 3 pump outputs, 2 button inputs, 1 LED, float input,
per-line prime volume, calibration, daily cap, tank counter).

## 1. Mechanical

- **Should fix — dock plate 0.5 mm off its supports.** `bulk_h = tray_h -
  0.5`: bulkhead and crossbar top out at 65.5, plate underside at 66. The
  plate must sag 0.5 mm before "three supports" exist. Strip estimate for
  the 125 mm bay (y 40→165) under ~6.3 kg (5.7 L + ~0.6 kg bin/lid): 0.46 mm
  solid, ~0.8 mm at 15 % infill, then PETG creep. Set the gap to 0.2 or make
  the plate 5–6 mm; the walls, bulkhead and crossbar print in the same layers
  so they are coplanar anyway.
- **Should fix — curb clearance is 1 mm on an estimated dimension.**
  `rsq(bin_bot + 2, …, bin_r + 1)`. The real CamSquare base is a stacking
  recess whose size and corner radius haven't been measured; PETG shrink on a
  197 mm bore is ~0.6–1 mm on its own. Use bin_bot + 5 and a generous inner
  corner radius. The 6 mm-offset self-test still passes against a
  sharp-cornered modelled bin.
- **Should fix — cover is taller than the tray.** `cover_w = 66` centred on
  `pump_z = 34` spans z 1…67; the tray is 66 tall. Probe: 310 mm³ of cover
  above z=66 (in front of the plate/column-floor line) and 137 mm³ below
  z=1.5 (over the bottom fillet). The three surface-mounted 2 mm plates cut
  across the plate seam by 1 mm and hang at the fillet. Make the cover ≤62
  tall (z 3…65) or recess it 2 mm into the wall so it sits flush.
- **Should fix — cover screw count is inconsistent.** Model drills 4 holes
  per cover; README and scad comment say "two"; BOM says "6 × M3×8". Model =
  12 screws. Also: M3 machine screws self-tapped into 2.8 mm PETG holes,
  removed at every tube change, will strip; the ribs (8 wide) are too thin
  for inserts — make them 10 wide with 4 mm insert holes, or use 2 screws +
  a hooked lower edge.
- **Consider — pump hangs on two 3 mm-deep self-taps.** Lower pair only,
  into a 3 mm bulkhead (2.5 threads). All four flange holes are reachable
  through the opening (the corners' r=4 arcs are centred on them); use all
  four, or M3 with nuts behind (reachable from above with the plate off).
- **Consider — no fillet on any can top, chase top, the collar's four
  vertical edges, the spout, or the sleeve.** Probe: the front can's outer
  top 1 mm × 1 mm ring is 100 % material. The can rims at z=315 are exactly
  where hands go for bottle changes; the chase tops chafe the tubes. The
  owner's rounding rule is not met and `verify.sh` doesn't check it.
- **Consider — the collar is a solid 30 × 17 × 249 mm block**: ~100 cm³,
  ~126 g, doing the job of a 4 mm shell around a 16 mm chase.
- OK: walls 3, floors 4, posts 10×10/Ø4 (3 mm walls), every post against a
  wall (verified), 4 mm insert holes (spec 4.0–4.2; after PETG shrink ~3.8,
  expect to ream).

## 2. Printability (P1S, no supports, as exported)

- **Blocker — the sleeve's rim ring floats.** The 6 mm ring at z 237…243
  (r 44.5…47.25) sits 15 mm outside the cup (r 29.75) and touches only three
  2 mm fins. 512 mm² of flat down-facing area at z≈237 — a curved 2.75
  mm-wide "bridge" of three ~80 mm arcs with nothing under them. Curved
  bridges don't bridge; the ring will droop into spaghetti. `verify.sh`
  passes it because its threshold is a total of 800 mm². Fix: carry the ring
  on a 45° conical skirt from the cup wall, or delete the ring (the fins
  already locate at r=47.25) and put a lift tab on one fin.
- Should fix — sleeve fins are 2 mm × 243 mm; from z 4…83 the part is three
  free 2 mm blades joined at the axis. Prints, but flimsy/twisty; 3 mm or
  four fins.
- Consider — 42 mm flat bridges over each pump opening: the P1S will bridge
  3 mm-deep spans, but they'll sag 0.3–0.5 mm behind the cover. Arch or
  chamfer the top of the opening; same for the Ø16 grommet hole. The
  teardrop helper was removed rather than used.
- Consider — PETG shrink on hardware holes: light pipe Ø8 in Ø8 (24 mm³
  interference at a 7.6 printed hole), GX12 Ø12.2 for a 12 mm thread,
  buttons Ø12.5. Add 0.4 to every panel hole.
- Consider — sleeve OD 94.5 in a 96 pocket (0.75 radial) on a 243 mm-deep
  press: PETG-on-PETG friction, no draft. Use 1 mm and a draft on the pocket
  or three contact ribs.
- Cover exports correctly (fillet and countersinks up, 0 mm² unsupported);
  the scad comment "outside face on the bed" is wrong.
- Warp: 225 × 225 tray and plate in PETG — brim is documented; fine on the
  textured plate.

## 3. Plumbing

- **Should fix (top of list) — forward siphon is still only held by roller
  occlusion, and the README claims otherwise.** README: "A primed line can't
  siphon in either direction." An outlet ending in air only stops Rise→doser
  backflow. A siphon runs whenever the *source* surface is above the
  *outlet* and the line is full; the peak height is irrelevant. Sources
  here: tank surface up to z≈250, a 125 mL bottle's liquid to z≈310, a 1 L
  bottle's to z≈300–315 — the highest liquids in the unit — against a spout
  at the Rise rim, which for every Rise model is well under 300 mm above the
  doser's floor. A worn pump tube (months) siphons up to 1 L of concentrate
  or 5.7 L of water into the Rise with no float, firmware or valve in the
  path. Cheap fix with no valves: run each outlet line up its own chase to a
  vented tee at the column top (above z=315), then down to the bundle — an
  anti-siphon loop; the column already has the chases. Or accept it
  explicitly and say so in the README instead of the opposite.
- **Should fix — the tank line's side exit kinks the tube.** Chase bore Ø12,
  exit hole Ø10 at z=301, open top at 315. A 6.35 tube turning 90° inside a
  12 mm bore into a 10 mm hole has a centreline radius of ~8 mm; 1/4"
  silicone kinks below ~15–20. Cut the exit as a slot from z=301 to the top
  with a rounded lip, or slope it 45° down.
- **Should fix — the bundle doesn't fit its grommet.** Three Ø6.35 tubes
  circumscribe 13.7 mm; with a 3 mm float lead ~15; braided sleeve ~16–18
  mm. The model draws an 11 mm bore in a 16 mm hole. Needs a ~22 mm panel
  hole with a ≥16 mm bore, or a split grommet.
- **Should fix — the Sprout feed crosses the front panel bay.** Sprout's
  chase exits at (244, 13) in *front* of the bulkhead, so its feed goes
  through seam hole (y=28, z=14) and runs 63 mm along the front wall to the
  Sprout inlet barb — under the Dose button's lugs at x=200 (~1 mm
  clearance to the modelled button; real 12 mm buttons are 20+ mm long with
  lugs and wires) and through Sprout's own outlet loop box (876 mm³
  overlap). It also passes the Thrive cover rib by 0.01 mm. Move the Sprout
  chase to the front can's back-left (x_cen+19, ~95) so it exits behind the
  bulkhead, then feed the barb through the pump's own slot.
- **Should fix — outlet lines run through the boards.** Water and Sprout
  outlets enter the column tray at (y=110/130, z=16) and must reach the
  grommet at (323, 225, 30). Straight runs hit the electronics; a 20 mm
  corridor along the right wall behind the bulkhead is blocked by ULN B
  (1,375 mm³ overlap). Thrive's two tubes from its slot at x=326 run
  straight at ULN B (x 303…338). Everything has to climb over the boards at
  z 26–42 with the 12 V wiring under it. Reserve a corridor: shift the
  boards left ≥20 mm or put ULN B on the left wall.
- Should fix — bottle change needs ~130 mm of tube slack that has nowhere
  to live. The pickup is through the cap; to swap a bottle you unscrew the
  cap and lift cap+dip tube 122 mm clear. The tube's other end is fixed at
  the pump barb via the chase, so the slack must be an arch standing 150+
  mm above the column, or the tube yanks the barb. Nothing is modelled for
  the caps, dip tubes, or the 1 L cap thread. A product needs a fixed
  cap-with-dip-tube per pocket (ink-tank style) with a short
  quick-disconnect jumper.
- Consider — middle seam bolt at (y=112.5, z=56) sits directly under the
  tank chase (235, 112.5); a nut's corners reach x=230.4, the tube's edge at
  231.8: 1.4 mm. Move the bolt to y≈95 or 130. Bolt heads/nuts are still
  not modelled anywhere.
- Consider — dose accuracy/priming: lines to the rim stay full after a run
  (outlet higher than the pump), so accuracy is good once primed, but the
  README's "a dose leaves the line after every run" is wrong; each nutrient
  line holds ~8–20 mL (ID unspecified — say which 1/4" OD tube: 1/8" or
  3/16" ID), a meaningful fraction of a 125 mL bottle on first prime and on
  every bottle change.
- Consider — lifting the tank: bin must rise ~190 mm to clear the pickup;
  lid can only tilt on the tube (Ø6.35 in Ø10). Filling in place around a
  tube with the lid tilted is the realistic workflow; say so.
- Consider — water pickup on the bin floor with no strainer/weight.

## 4. Usability

- **Should fix — USB is unreachable.** DevKit at y 150…205, connector face
  at y≈206, wall inner face at 222: 16 mm gap through a 12 × 8 slot. No plug
  seats. `verify.sh`'s "USB slot lands on the DevKit's end" only compares
  x/z at the wall, not the board's reach. Moving the board back 16 mm
  collides with the (233, 217) post, so the board also moves right and the
  slot with it.
- Should fix — standoffs are solid Ø5 cylinders, no holes; the README's
  "M2.5 for the boards" can't happen. And a stock ESP32 DevKitC has no
  mounting holes and pins-down headers (the model draws pins up); 6 mm
  standoffs won't clear pins-down. Needs a printed carrier/clip for the
  DevKit and 2 mm holes in the ULN/buck standoffs.
- Should fix — the sleeve can't be lifted out. Its notch is a gap in its own
  rim ring, 2 mm below the column's rim, with no matching scallop in the
  can; the front window is 12 mm (no fingertip). Add a tab above the rim or
  a can scallop.
- Consider — the back sleeve as placed has its window facing the front can
  and a fin sitting in the column's back window; the user must rotate it
  180° and nothing keys or says so.
- Consider — panel wiring (6 wires) has no route from the front bay to the
  seam wire hole except through Sprout's tube slot; add a wire hole in the
  bulkhead near x≈205.
- Consider — a rim notch that drains spills "off the outside of the case"
  dumps them on the floor behind the unit; a 5 mm rim and no notch is
  better.

## 5. Safety and reliability

- **Should fix — a Thrive head leak reaches the electronics.** The front bay
  holds ~84 mL to the tube slot's sill (z=20), then flows through the slot
  into the board bay, whose 6 mm standoffs give ~120 mL more; a torn pump
  tube under a 1 L bottle (gravity feed) delivers 1 L. Floors are
  deliberately sealed. Raise the boards (20 mm standoffs / wall-mount), add
  a sill or a drained sump in each pump bay, or a wet sensor on the floor.
  Same leak in the dock reaches the Dose button lugs at z≈16+.
- Should fix — the float is the only overflow protection and has no mount.
  The 4 mm hole in the spout is for the lead only; a float switch body
  needs a bracket at the Rise's fill line, and the lead must be threaded
  through spout, sleeve and grommet before the GX12 is soldered. Put the
  float on a printed stalk under the spout so nothing is drilled into the
  Rise. Firmware daily cap remains essential.
- Consider — no dry-tank detection (dead-reckoned counter). A $2 float
  through a second lid hole is cheaper than the load cell in "Next".
- Consider — translucent Cambro next to a grow light; plain water limits
  algae but the pickup line will grow biofilm. Opaque bin or shroud.
- Consider — WiFi antenna end of the DevKit faces the motors and the tubes;
  flip the board (or its carrier) so the antenna faces the wall.
- OK: 12 V/2 A, polyfuse 1.5 A, one pump at a time, buck to VIN, float
  fail-safe open — all in the BOM/plan but not in the model.

## 6. Product viability

- Bought parts ≈ $110–120; printed 2,516 g solid (harness), realistically
  ~2.0–2.2 kg at 15 % infill, ~80–110 h on a P1S. Column 928 g alone (2 mm
  can walls −190 g, collar as a shell −100 g gets it to ~600). The previous
  review's <1.5 kg target was not met; the sleeves were fixed (356 g vs 2.2
  kg) and the trays grew.
- A manufacturer's objections stand: seven bolted prints with inserts,
  12+7+6 screws, a drilled third-party lid, exposed DevKit and stepper-kit
  drivers, caps with home-made dip tubes, a float installed in someone
  else's reservoir, no level sensing, no anti-siphon.
- Look: a 345 × 225 × 315 box with a food-storage bin on it and two bare
  cans with a rectangular block between them; tube arches over the column
  and a tube crossing to the lid are visible. The base proportion (66 tall)
  with covers spanning its full height reads as three doors. Works as a
  prototype beside a Rise; as a product the tank and the column need a
  skin.

## 7. What verify.sh still doesn't check

1. Tube runs as swept paths with a bend-radius limit (Sprout feed, outlet
   runs, exit bend, chase-to-seam) — every routing issue above is invisible
   to it.
2. Bolt heads and nuts vs tubes/pumps.
3. Board reach to the USB slot (the current check only tests the slot).
4. Bundle cross-section vs grommet bore.
5. Overhang as *largest single flat down-facing region*, not a total (the
   sleeve ring: 512 mm² in one ring passed an 800 mm² total).
6. Edge rounding on exposed edges (owner rule).
7. Plate-to-support gap as a number (0.5 mm).
8. Bought-part sensitivity: curb vs bin_bot ±2 mm, exit vs lid_above.
9. Print time / infilled mass, not just solid.
10. Spill containment: pump-bay volume to the slot sill vs board height.
11. Source-surface height vs spout height (siphon condition).
12. Hardware hole diameters with shrink allowance.
13. BOM vs model (cover screw count).

## Top 10, ranked

1. **Anti-siphon.** Bottles and tank are the highest liquids in the unit;
   the spout is lower. Vent each outlet line at the column top (tee above
   z=315 via the chases) and fix the README's false claim.
2. **Sleeve rim ring floats** (512 mm² flat overhang at z=237): carry it on
   a 45° skirt from the cup or delete it. Won't print as is.
3. **USB unreachable** (16 mm): move the DevKit to the back wall, fix the
   post collision, check reach not alignment.
4. **Tube corridors**: move the Sprout chase behind the bulkhead; reserve a
   20 mm corridor to the grommet by moving ULN B; model the routes.
5. **Bundle grommet**: ≥16 mm bore (three 1/4" tubes = 13.7 mm + lead).
6. **Tank-line exit**: slot it to the top or slope 45°; 8 mm bend radius
   kinks.
7. **Leak containment**: raise or wall-mount the boards, sill or sump per
   pump bay; a 1 L bottle can gravity-drain through a torn pump tube.
8. **Plate support and curb**: close the 0.5 mm gap (0.2) or go 5–6 mm
   plate; give the curb 2.5 mm clearance and measure the bin.
9. **Covers and screws**: cover ≤62 tall or recessed; decide 2 or 4 screws
   (model says 4, README 2); inserts in wider ribs.
10. **Bottle-change mechanics and the float mount**: fixed cap-with-dip-tube
    per pocket with a short jumper; float on a stalk under the spout;
    standoffs with holes and a DevKit carrier; fillet the can tops.

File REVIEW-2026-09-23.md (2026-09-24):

# Rise Doser design review, 2026-09-23

An independent review of the design as of this date (model, README, verify
harness, firmware), by a reviewer with no part in the design. Kept here
because the next round of changes is driven by it. Nothing in it has been
acted on yet.

Files reviewed: `rise-doser.scad`, `README.md`, `verify.sh`, `export.sh`,
`stl/*`, `firmware/rise-doser/{README.md,rise-doser.yaml,doser.h}`. The
reviewer rendered the assembly and each piece, ran STL volume, bed-contact
and overhang statistics, and ran extra boolean probes in the style of
`verify.sh`.

Note: the firmware's pump timeout is 45 min (`doser.h`), not 30.

## 1. Mechanical

**Blocker: the column as exported stands on its two rails, not its floor.**
The export shifts by `-tray_h + 3`, so the rails (2.5 × 176 × 3 mm) touch
the bed and the entire 120 × 200 floor is 3 mm in the air. From
`stl/column.stl`: bed contact 714 mm²; downward-facing floor at z = 3 mm:
22,594 mm². `verify.sh` passes because it only checks lowest z = 0. It
cannot print without supports. Fix: delete the rails; locate the column with
the tray's four posts extended 3 mm above the wall and matching blind
recesses in the column floor.

**Should fix: rails are dimensionally wrong.** 0.3 mm clearance to a 114 mm
printed cavity is inside PETG shrink (~0.4 mm). Interfere or rattle.

**Should fix: the column's screw heads stand proud on the pocket floor.**
The counterbore starts at z = 69.99, above the pocket floor (z = 70), so it
cuts nothing. Four pan heads sit on the floor; the sleeve rocks on them. The
screws are also 3.6–4 mm from the pocket wall: a driver can't reach them
down a 94 mm bore 216 mm deep. Move them ≥ 20 mm inboard, countersink.

**Should fix: dock plates are 4 mm PETG spanning ~190 mm under 4 kg with
nothing under them.** Material between bulkhead top (z = 50) and plate
underside (z = 62): 0. Deflection ~1 mm solid, 2–3 mm at 15 % infill, and
PETG creeps: expect a permanent dish. Raise `bulk_h` to `tray_h - 0.5` so
the bulkhead carries the plate mid-span; add ribs under the plate.

**Should fix: the curb is 0.9 mm tall.** Bead centred at z = 69.5, plate top
at 70. Won't locate a Cambro with a real foot ring; the 6 mm-offset check
passes only because the bin is modelled sharp-cornered and flat. Make it
3–4 mm, or a recessed pocket.

**Should fix: heat-set posts are 8 × 8 with a 4 mm hole: 2 mm walls.**
Inserting will bulge or split them. 10 × 10, or gusset to the wall.

**Consider: seam joint.** Two M3 at z = 30 only; nothing ties the tops of
adjacent trays, so the 512 mm base can hinge about the bolt line when lifted
with 8 kg of water in it. Add a bolt near the top, or make the plates/column
overlap the seam. Bolt heads and nuts aren't modelled; the front one sits
13 mm from a pump's tube.

**Consider: bulkhead.** After the U-slot and the tube window, each pump hangs
on two M3 self-tappers in a 14.5 mm strip of 3 mm wall. Adequate for 150 g,
but see access. The comment "diagonal pair used" is stale; both screws are
the lower pair.

**Consider: the centre tray has two 9 × 36 mm slots through its floor to
the outside.** The column's slot is at z = 62..71, the tray's at z = -1..5;
no tube uses them. They're open holes in the underside, and `verify.sh`
line 63 requires them. Delete, or call them drains and add matching ones
under the docks.

## 2. Printability

**Blocker: column orientation** (above).

**Should fix: the column's top slab bridges 6,634 mm² of void**, longest span
~57 mm at the waist, in PETG. The tube holes and side exits land in that
region: stringy underside, ragged holes. Add ribs, roof the voids with 45°
chamfers, or make the column a figure-8 (two tangent cylinders plus a rear
chase) — which also halves its mass.

**Should fix: mass.** Column 869 cm³ (~1.0 kg as printed, all 3 mm walls);
each sleeve 1,094 cm³ (a solid 93 mm cylinder, ~340 g at 15 %); dock trays
333 cm³; centre tray 239; plates 158 each. ≈ 2.8 kg PETG and ~100 h. The
column and sleeves are ~60 % of it. The sleeve should be a thin cup on
fins (~40 g).

**Consider:** bottom fillet r 2.5 starts at a horizontal tangent (60–80°
overhang for the first 0.5 mm): use a 45° chamfer or r ≤ 1.5. Seam tube
holes and button holes are plain circles (the teardrop helper exists,
unused). Sleeve-to-pocket fit is 0.5 mm radial: press fit after shrink; use
≥ 1 mm. Everything needs a brim; the README doesn't say.

## 3. Plumbing

**Blocker: the tee mixes Sprout and Thrive concentrate undiluted.** The
firmware README promises they never touch undiluted; the tee does exactly
that in ~470 mm of shared line (3–4 mL). Two-part concentrates are kept
apart because calcium in one precipitates with phosphate/sulfate in the
other; that precipitate forms in the shared line and clogs it. The dead
volume is also about one 125 mL-bottle dose, so each dose arrives one run
late, and roller leakage pushes one concentrate toward the other bottle.
Give each nutrient its own line and lid hole (4 exits on the right, 4 holes
in the mix lid).

**Blocker: submerged outlets create siphons the float can't stop.** Levels
up to z ≈ 247, tube peak 272, pumps at 34, a 1 L bottle's liquid up to ~280.
Once primed, a full tube siphons regardless of the peak; the only thing
holding it back is roller occlusion in an $8 pump whose tube flattens with
age. So: the water tank drains into the mix tank until levels equalise; a
full 1 L bottle siphons concentrate on its own; the transfer line siphons
mix → Rise or Rise → mix depending on which surface is higher, unseen by
float or firmware. "Tubes sit on the bottom" must apply to pickups only.
Every inlet (water and nutrients into the mix tank, transfer into the Rise)
must end above the maximum liquid level so the down-leg drains. This also
improves dose accuracy.

**Should fix:** mix-tank inlets sit 14 mm from the transfer pickup on the
floor; concentrate pools unstirred and the transfer takes a concentrated
slug first. Inlets above the surface, pickup at the far corner, ideally an
air stone.

**Should fix: barb-to-window path forces a ~9 mm bend radius** (barbs at
±29, window at ±38, barb y = 19, bulkhead y = 40). 1/4" silicone kinks below
~15–20 mm. The harness tests two straight stubs, not the curve. Move the
window outboard 20–25 mm or the bulkhead back; add a swept-path check.

**Should fix: exit-to-lid geometry.** Exit centre 272, lid top 263.3: 8.7 mm
of drop over 30 mm; tubes will loop up on the lids. The assert margin is
1.7 mm on estimated lid dimensions; a real SFC2 lid is likely thicker than
6 mm. There's 33 mm of bed headroom: raise `col_h` ~25 mm or angle the
exits 45° down.

**Consider:** no prime step in the Dose workflow (~6 mL of concentrate to
fill a line). Backflow water ↔ mix through the water line (solved by the
air gap). No flush routine; nutrient line tips crust, the water line grows
biofilm. Lifting a tank: the bin rises ~190 mm before the pickups clear,
then drips onto the plate over the electronics. README still says "bottom
valve", "valve pin", "2 × M3 per valve", "pump heads come through the
front", "motor holes are teardrops", "tube groove": none of it in the model.

## 4. Usability

**Should fix: the panel has no firmware.** No `binary_sensor` for the two
buttons, no output for the light, no LED in the BOM. "Dose" is ambiguous.

**Should fix: the electronics have no standoffs.** Boards float 6 mm up on
nothing; the DevKit's headers go 6 mm down into air.

**Should fix: pump flange screws are unreachable.** Both at z = 13, axis
along y, behind the bulkhead, 9 mm above the floor and 7 mm below the motor,
in a bay open only at the top. And the pump's cover (where the wear tube
lives) faces a closed wall 2 mm away: every tube change means lifting a
4 kg tank and its tubes, the plate off, the pump unscrewed from behind.
Peristaltic tubes wear in months. Use the standard mount: head through a
removable front bezel, screws from the front, behind a snap cover if it
must be hidden.

**Should fix: no wire route out of the left tray.** The Water and Sprout
leads must share the two 14 mm seam holes with two 6.35 mm tubes each. Add
a wire hole per seam and a cable path for the panel and jack.

**Consider:** a 3.8 L tank is two 2 L batches; still weekly refills. A fill
plug in the water lid avoids moving tubes. Dry tanks aren't detected: a dry
water run followed by a nutrient dose leaves concentrate alone on the mix
floor with the counter at 2 L. A float per tank fixes most of §5 too.
Buttons at 20 mm pitch with 15.5 mm bezels; the USB face is 6 mm inside the
wall, most micro-USB plugs won't seat through 3 mm + 3 mm of air.

## 5. Safety and reliability

**Should fix: electronics sit directly under the mix tank.** No lip or
gasket at the plate; spills, tube drips, condensation and any overfill (the
mix counter is dead-reckoned; `mix_capacity` defaults to 4.0 L for a 3.8 L
bin) run over the plate edge into the tray with the 12 V rail. Move the
electronics to the centre tray or a sealed rear bay, give the plates a drip
lip/drain, default `mix_capacity` ~3.0 L, and add the wet sensor before
first use.

**Should fix: Rise overflow.** The float is fail-safe open, but not for a
float stuck "not full" (fouled by roots or algae, common). The other cap is
`min(want, mix_ml)`, so the worst case is 3.8 L into a full reservoir.
`transfer_amount` defaults to 0 = all. Default ~1 L, add a rolling 24 h cap.

**Consider:** 45 min at 100 mL/min = 4.5 L, more than either tank; the
timeout protects nothing tank-sized. Algae in translucent bins under grow
light, with mix sitting indefinitely: opaque bins or a shroud, or
mix-and-transfer as one action. Stalled INTLLAB pumps draw ~1 A; two
paralleled ULN2003 channels are rated 1 A, no fuse, no current sense: add a
polyfuse, consider MOSFETs. The 5 A adapter is 2× what's needed.

## 6. Product viability

- Bought parts ≈ $95, plus ~2.8 kg PETG (~$60) and ~100 h of print time. Not
  sellable as printed; the print time alone is the objection.
- A manufacturer would object to: seven bolted prints with inserts (→ two
  moulded modules, bosses and snap fits); drilled third-party lids (→ custom
  lid with grommets and a fill plug); a DevKit and stepper-kit drivers with
  an exposed USB (→ one PCB: ESP32 module, MOSFETs, fuse, jack, buttons,
  LED); pumps that aren't user-serviceable (→ front-loading cassettes); no
  level sensing; electronics under the wet zone; translucent tanks; a float
  installed in another company's reservoir (liability; Rise geometry varies
  by model).
- **The mix tank is the biggest cost driver:** it adds a tank, a pump, two
  lid holes, the tee, half the plumbing and most of the siphon and
  stratification risk. The Rise reservoir is ~19 L of circulating water and
  the Rise app already has you squirt concentrate straight into it. Dosing
  into the Rise directly with a water top-off is a 3-pump, 1-tank product at
  about half the parts. Worth an explicit decision.
- For a moulded version the layout survives, but: 2–2.5 mm walls with ribs,
  drafts on the pockets, no through-slots in floors, moulded cable and tube
  channels, a sealed electronics bay, a bigger water tank.

## 7. What `verify.sh` doesn't check

1. Bed-contact area per piece (would have caught the column).
2. Unsupported downward-facing area above z = 0.
3. Tube continuity as a swept path with a bend-radius limit, not disjoint
   straight stubs.
4. Bolt heads and nuts vs tubes and pumps.
5. Wire routes and a cable cross-section budget through the seams.
6. Plate support mid-span.
7. Curb height as a number.
8. Board standoffs (the boards check passes *because* nothing supports them).
9. Tool access: a driver-shaped cylinder to each column screw and each
   flange screw.
10. Lid lift (bins only; lids clear by 3 mm).
11. Volume, mass and print time per piece.
12. Sensitivity to the estimated bought-part dimensions (the exit-height
    assert has 1.7 mm of margin).
13. It enforces a mistake: line 63 requires a through-hole in the centre
    tray floor.

Stale in the README: "print the centre tray and one sleeve first, they test
the pump holes and flange screws." The centre tray has no pumps.

## Top 10, ranked

1. Re-orient the column so it prints on its floor: delete the rails, locate
   on the tray posts (extended 3 mm) with recesses in the column floor.
2. Remove the tee; separate lines and lid holes for Sprout and Thrive.
3. End every inlet above the liquid line; only pickups sit on the bottom.
4. Get the electronics out from under the mix tank; drip lip and drain on
   the plates; wet sensor and a mix-tank float before first use.
5. Make the pumps serviceable: head through a removable front bezel, screws
   from the front, snap cover if it must be hidden.
6. Cut the plastic: figure-8 column, thin-cup sleeve; target < 1.5 kg.
7. Support the dock plates: bulkhead to the plate underside, ribs, and a real
   3–4 mm curb.
8. Fix the column screws: real counterbores, ≥ 20 mm from the pocket wall.
9. Standoffs, wire holes, and panel firmware.
10. Bound the failure modes in firmware: `mix_capacity` ≤ 3.0 L for a 3.8 L
    bin, `transfer_amount` ~1 L with a daily cap, the 45 min timeout as a
    backstop only. Then decide deliberately whether the mix tank should
    exist at all.

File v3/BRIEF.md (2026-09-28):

# Hydro Doser v3, the brief

No geometry, no code. This is everything a clean design starts from: the
parts it has to fit, the printer it has to come off, and the rules it has
to keep. Nothing from v1 or v2 carries over except these numbers.

## 1. Bought parts, measured

Marked *(est.)* where the number came from a listing or a drawing rather
than calipers. Measure those before the first print.

### The tank: Cambro CamSquare 6 qt, 6SFSPP190

| | mm |
|---|---|
| outside at the rim | 213 × 213 |
| outside at the base | 195 × 195 *(est.)* |
| height | 184 |
| corner radius | 14 *(est.)* |
| rim, wall thickness | ~2 *(est.)* |

The unit does not sit on the tank. It stands on its own feet and can be
used with any reservoir, or none; the water inlet leaves through the
back with the outlets.

### Pumps: INTLLAB 12 V peristaltic, three of them

| | mm |
|---|---|
| head | Ø38 × 23 long |
| flange (diamond) | 55 wide × 41 tall × 3 thick |
| flange hole pitch | 48.5 |
| flange holes | Ø3.2 |
| motor | Ø27 × 44 long |
| nozzles | two, 10 off the head's face, 16 apart |
| tube | silicone, 3 ID × 5 OD |

The motor goes through the wall; the flange sits on the wall and takes
two M3 screws; the head and its two nozzles stay on the accessible side.
The tube loops off the two nozzles and needs about 30 mm of room beyond
the head.

### Electronics

| Board | mm | Notes |
|---|---|---|
| ESP32 DevKitC | 55 × 28 | pin headers down, 8.5 tall; USB on a short end |
| ULN2003 driver | 35 × 32 | ~15 tall with its header |
| 12 → 5 V buck | 45 × 20 × 12 | |
| KY-040 encoder | pcb 31 × 19 × 1.6 | body 6.5 above the pcb; threaded bushing (M7) to 11.5; D shaft Ø6, flat at 4.5, to 20 (cut to 16 for the thin knob); shaft centre 9.5 from the pcb's top edge |
| 0.96" OLED | pcb 27.3 × 27.8 × 1.6 | glass 26.7 × 19.3 × 1.5, centred 0.75 below the pcb's centre; active area 21.7 × 10.9, centred 1.45 above; 4 pins on the top edge |

### Panel hardware

| | hole |
|---|---|
| 5.5 × 2.1 DC jack | Ø11.5 |
| GX12-6 (float switch + TDS probe) | Ø12.2 |
| pH probe's stock cable, BNC through, grommet round it | Ø16 |
| three outlet barbs, uxcell M6 bulkhead (B0F5X3DXQ5) | 3 × Ø6.4 |

### Fasteners and the rest

| | mm |
|---|---|
| M3 heat-set inserts | hole Ø4, 5 deep |
| M3 self-tappers (flanges) | pilot Ø2.6 |
| nutrient bottles, 125 mL, two | Ø48 (measured) × 122 *(est.)* |
| garden reservoir rim (for the spout) | 4 thick, 30 drop *(est.)* |

## 2. Layout rules

- Every screw hole and every foot sits at the centre of its corner's
  radius. Never near an edge.
- As compact as the parts allow.
- The pumps mount as in the first design: rolled 42° about their axes,
  so the flange's two holes sit on a 42° line.

## 3. Printer

- Bambu P1S: 256 × 256 × 256 usable. Every piece fits flat on that bed.
- PETG. No supports. Each piece prints in the orientation it is exported
  in, and the export says which face is down.
- Overhangs at or under 45°, or chamfered to get there. Bridges under
  40 mm. Every piece keeps at least ~6 % of its footprint on the bed.
- Clearances: 0.2 on a magnet pocket, 0.3 on a through-hole for a bought
  part, 0.4 on a sliding fit.

## 4. What it has to do

1. One printed enclosure on its own feet, the floor and the walls one
   piece, with standard foot pads (snap-in TPU pads) under the floor. No
   tank features. Anything that goes to a tank goes out the back.
2. Three pumps in a row, evenly spaced, heads toward one side, reached
   by taking the lid off. No side panel.
3. Ports in the back: the 12 V jack, the pH cable's hole and the GX12-6
   on one line, low, the jack and the GX12 between the pumps and the
   pH hole under the middle one; the three outlet barbs in a row above
   the middle motor, the water hole above them. The driver and the buck mount on the inner side walls
   in the bottles' section. Vent slots, as on a router, in both side
   walls beside the motors.
4. A faceplate carries the controls, the screen left of the knob and
   close to it, with even spacing around the knob. The screen, the knob
   and the ESP32 mount to the faceplate, the ESP32 behind the other two; the faceplate screws into the body with
   M3 countersunk screws into heat-set inserts, flush with the body, the
   seam chamfered on both sides.
5. The screen is flush, mounted from behind, with a window the size of
   its picture. The knob is Ø36, countersunk into the face, diamond-
   knurled on the exposed part, chamfered after the knurl.
6. The two 125 mL bottles stand inside the body in cup-holder cutouts in
   the lid, in the middle of the front. No holders, clips or brackets of
   any kind.
7. The lid snaps on, the same size as the body, flush: no shadow line.
   The faceplate is the only screwed piece.
8. Every 90° is filleted and every edge rounded. The body's vertical
   faces carry a fuzzy-skin texture band; the faceplate does not.
9. The bottles' tubes pass through plain holes in the lid, 16 mm out from
   each bottle, on its outer side: no channels on the cups. The water
   tube's hole is in the back wall, high, above the middle pump.
10. The wiring stays as built: ULN2003 IN1/2/3 from GPIO25/26/27; right
   pump Nutrient B, middle Nutrient A, left Water; +V chained to the pump
   + terminals; jumper on; 12 V to the board when the jack arrives.
   Reserve GPIO21/22 for the OLED and 18/19/23 for the encoder.

## 5. To measure before the first print

- The bottles' height and the cap's diameter.
- The reservoir's rim: thickness and drop.
- The pump: confirm the nozzle spacing and flange from the part in hand.

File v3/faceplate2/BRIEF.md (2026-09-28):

# Faceplate 2: brief

A new faceplate for the Hydro Doser v3 that carries every board itself:
no adapters, no parts on the body. Nothing is drawn until this is agreed.

## Fixed: it must fit the body as printed

| What | Value |
|---|---|
| Outline | 176.4 × 59.4, 3 thick, 8 mm corner radius, face edge rounded 1 |
| Screws | four M3 × 8 countersunk at the corner-radius centres, into the inserts already in the body |
| Opening in the band behind the wall | 152.4 × 35.4 (x 24.8 to 177.2, z 19.3 to 54.7): anything within 6 of the plate's back must stay inside it |
| Depth behind the plate | the bottle cups start 31 behind the plate at their nearest; nothing may reach them |
| Body | unchanged, no reprint |

## The parts it carries

| Part | Size | How it mounts |
|---|---|---|
| OLED 0.96" (SSD1306) | pcb 27.3 × 27.8, glass 26.7 × 19.3 | drops into a pocket from behind, 0.3 clear each side, 0.2 top and bottom; window the size of the picture |
| KY-040 encoder | pcb 31 × 19, 14 tall off the plate | bushing through the plate, its nut on the flat face inside the knob's base pocket, which holds it; no rib beside it, so its harness plugs in freely |
| Knob | Ø36 × 9.5, brown-red ring, black cap | sits 0.5 in front of the flat face: no recess, the face prints flat on the bed |
| ESP32 DevKit V1, 30-pin | 51.5 × 28.3 | four standoffs, M2.5 self-tappers, module toward the plate |
| DFRobot Gravity TDS board | 42 × 32 | four standoffs, M3 self-tappers |
| pH board (PH-4502C type) | — | not on the plate: the probe keeps its own cable, out the back wall |

Hole spacings for the three boards are still assumed (DevKit 46.9 × 23.7,
the two 42 × 32 boards 35 × 25). Measure them before this is drawn.

## Layout

Seen from the front, left to right: **screen, ESP32, knob.** The ESP32 is
hidden behind the plate, so the face shows the screen on the left and the
knob on the right, each the same distance from the plate's centre, with
the ESP32 between them behind.

The pH board is no longer carried: the probe keeps its stock cable, which
leaves through the back wall. The TDS board cannot stand over the screen: the left bottle cup
sits right behind it, and the screen's plug alone reaches 27 of the 31
available. It mounts instead on a fin standing off the plate's back at
the screen's end, outside the cup, printed with the plate. The ESP32's
middle stays open for the wiring to converge on its headers.

Built as `faceplate2.scad` (it uses the v3 model for the body, the knob
and the wall boards); `./verify.sh` checks it against them and writes
`../stl/faceplate2.stl`, face down.

## Rules

- One radius family: 8 at the plate's corners, 1.5 on every standoff's
  fillet into the plate.
- Every standoff, rib and pocket backed by a part; nothing decorative.
- Every plug reaches its ESP32 pins in one piece: the knob's 5-pin plug,
  the TDS board's 3-pin plug, the screen's 4-pin plug.
- Prints face down, no supports.

## Open questions

1. **Spacing on the face:** screen and knob each 45 mm from the centre
   (the default), or pushed out toward the ends?
2. **The two sensor boards:** over the screen and the knob (the default),
   or stacked behind the ESP32?
3. **Measurements:** the hole spacings of the DevKit, the TDS board and
   the pH board.

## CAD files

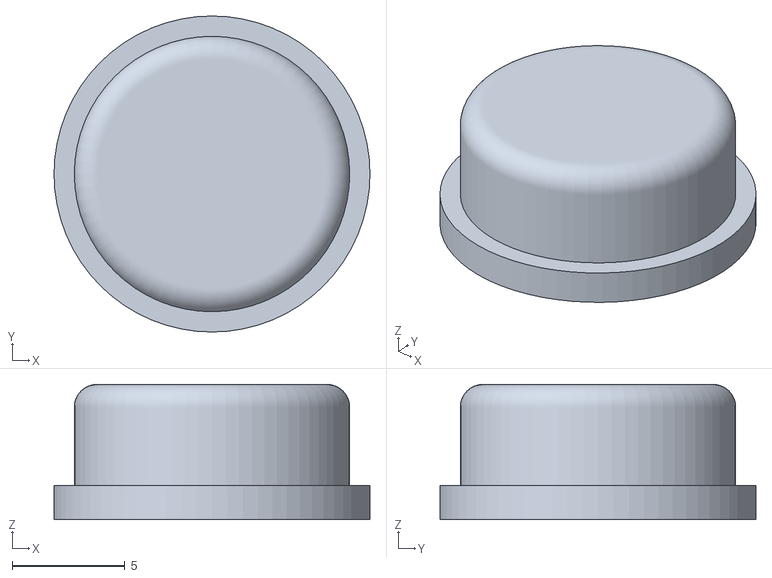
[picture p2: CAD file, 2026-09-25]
stl/button_cap.stl
14.0 x 14.0 x 5.99

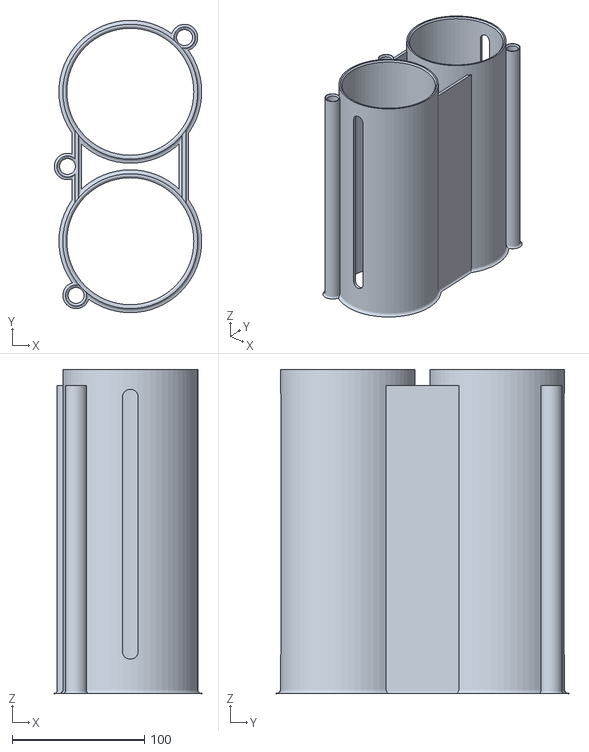
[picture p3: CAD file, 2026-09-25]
stl/two-colour/column_towers.stl
111.5 x 221.0 x 245.0

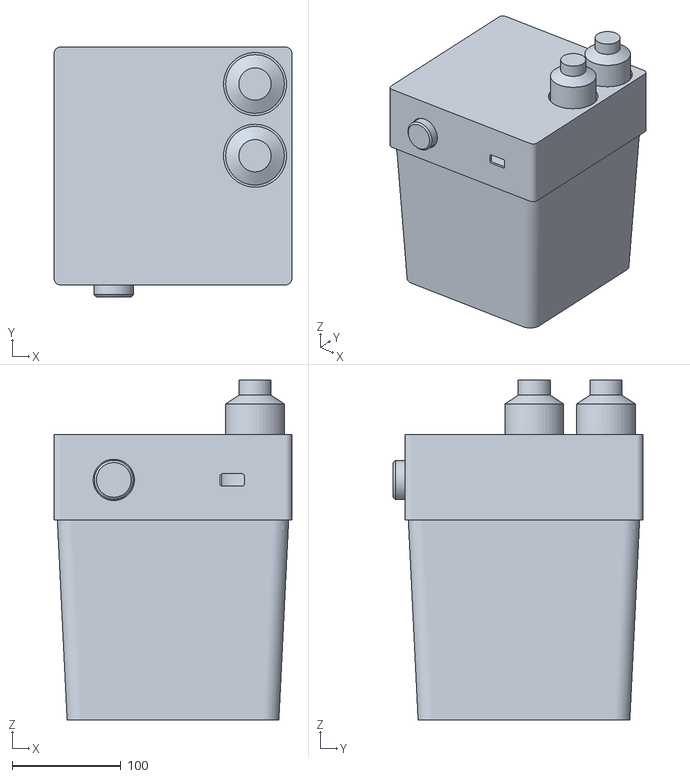
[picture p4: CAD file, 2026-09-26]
v3/mockups/opt1.stl
219.0 x 230.0 x 313.0

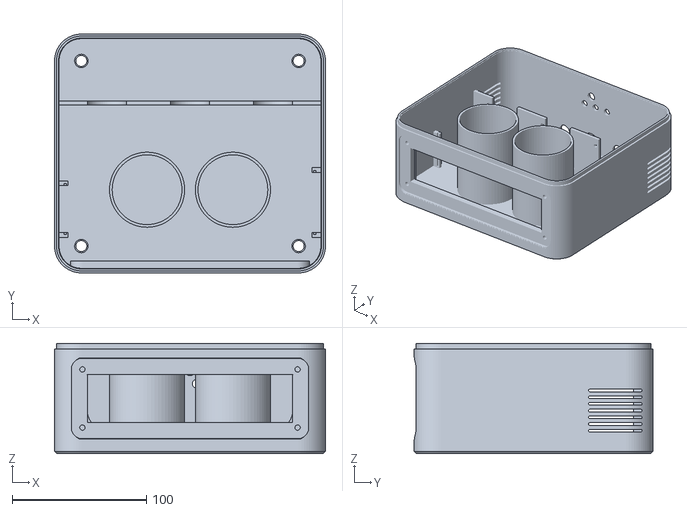
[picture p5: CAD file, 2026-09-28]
v3/stl/body.stl
202.0 x 178.0 x 82.0

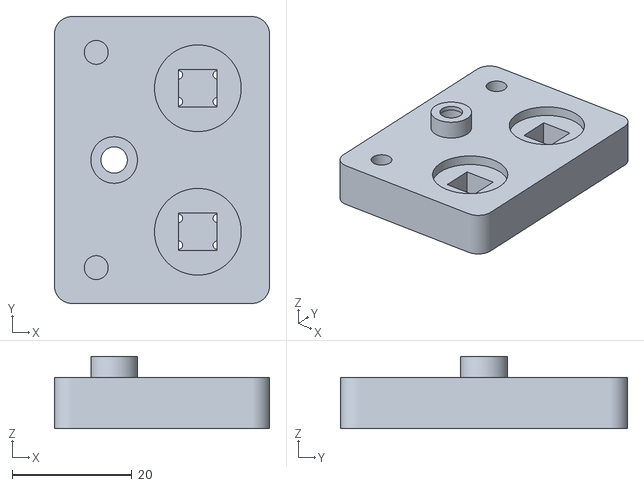
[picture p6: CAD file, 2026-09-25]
stl/panel_plate.stl
36.0 x 48.0 x 12.1

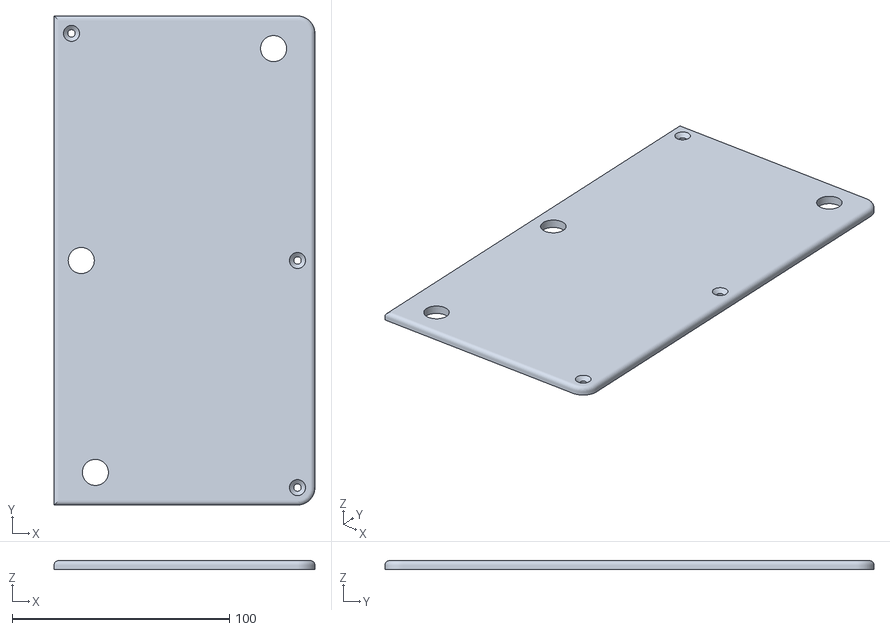
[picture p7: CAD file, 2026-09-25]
stl/two-colour/column_floor.stl
120.0 x 225.0 x 4.00

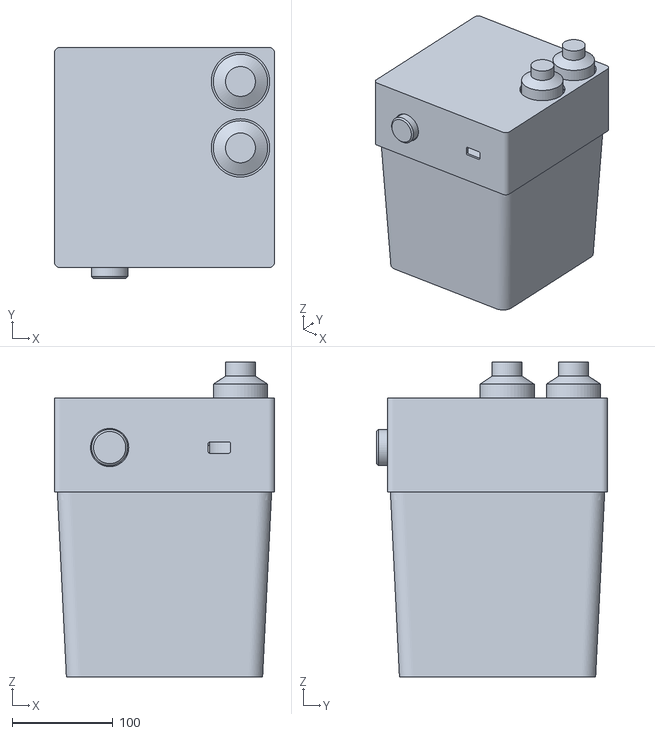
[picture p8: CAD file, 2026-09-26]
v3/mockups/opt3.stl
219.0 x 230.0 x 313.0

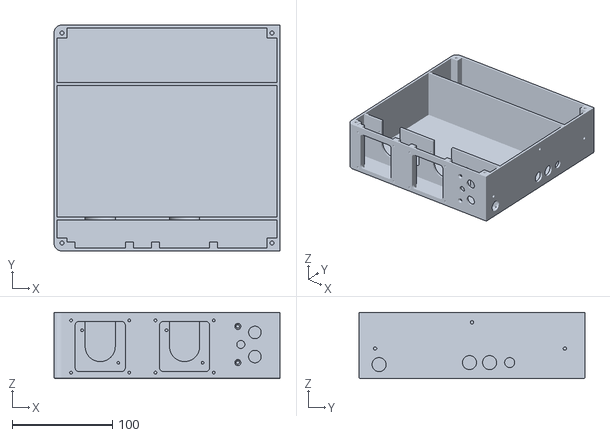
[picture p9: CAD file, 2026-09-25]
stl/tray_dock.stl
225.0 x 225.0 x 66.0

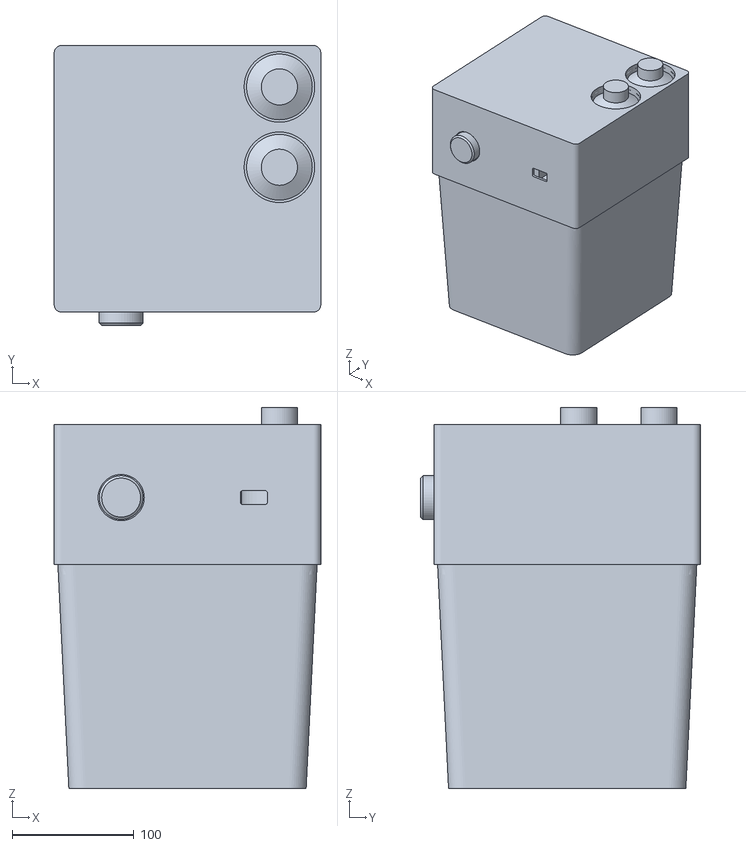
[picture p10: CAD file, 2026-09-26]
v3/mockups/opt2.stl
219.0 x 230.0 x 313.0

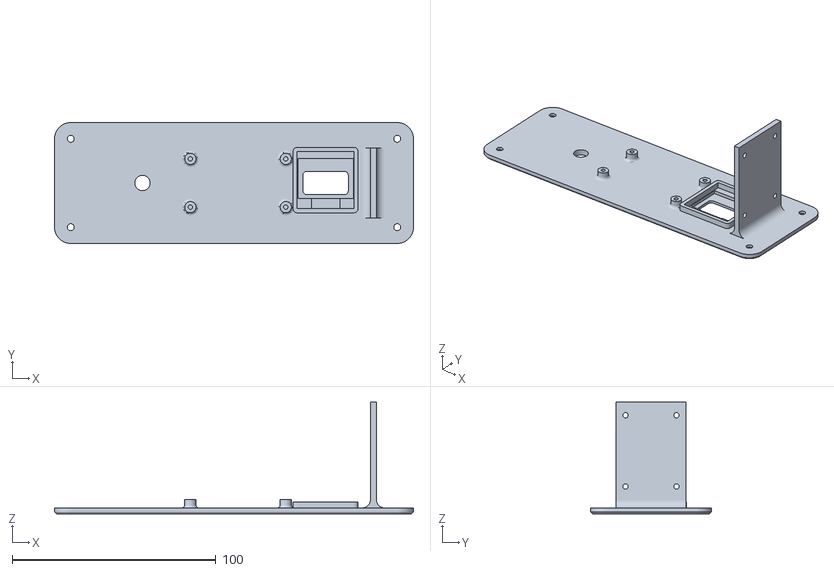
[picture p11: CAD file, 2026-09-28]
v3/stl/faceplate2.stl
176.4 x 59.4 x 55.0

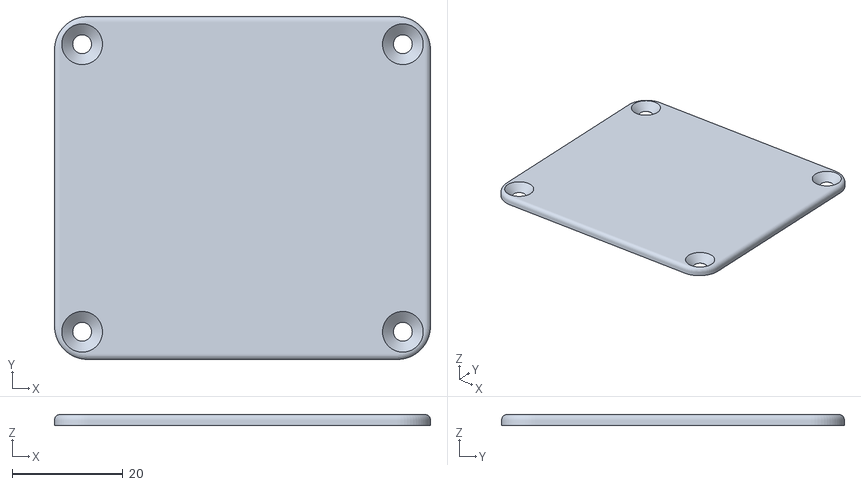
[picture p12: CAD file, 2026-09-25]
stl/cover.stl
68.0 x 62.0 x 2.00

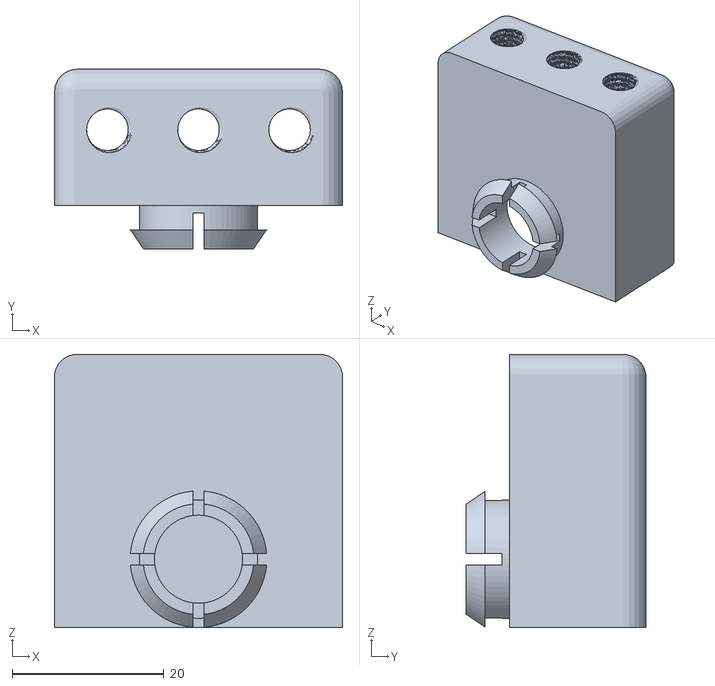
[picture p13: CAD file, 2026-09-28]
v3/stl/outlet-block.stl
37.9 x 23.7 x 36.0

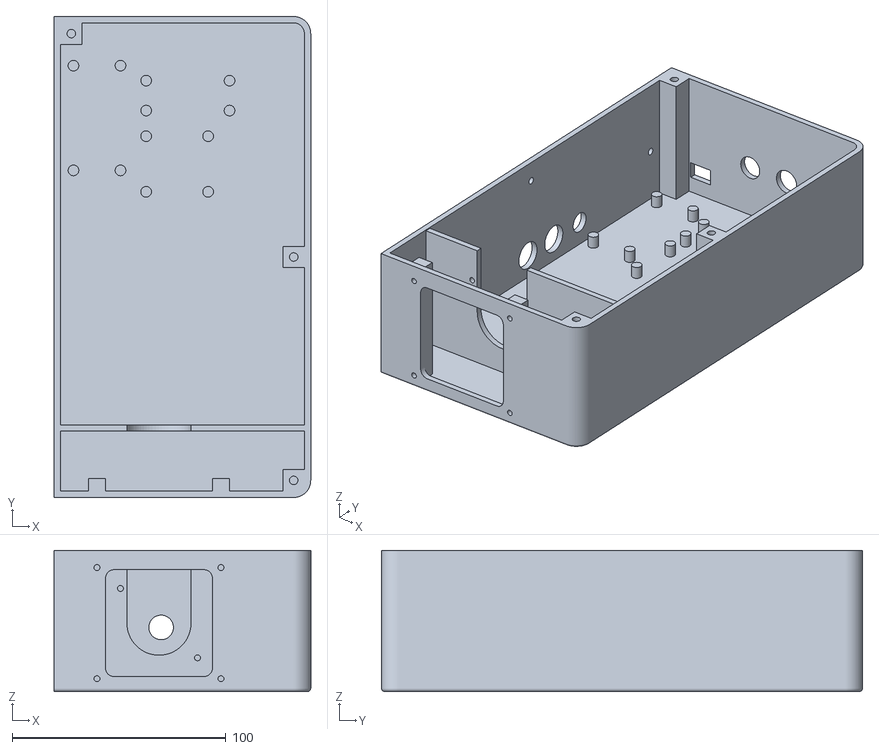
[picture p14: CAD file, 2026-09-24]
stl/tray_col.stl
120.0 x 225.0 x 66.0

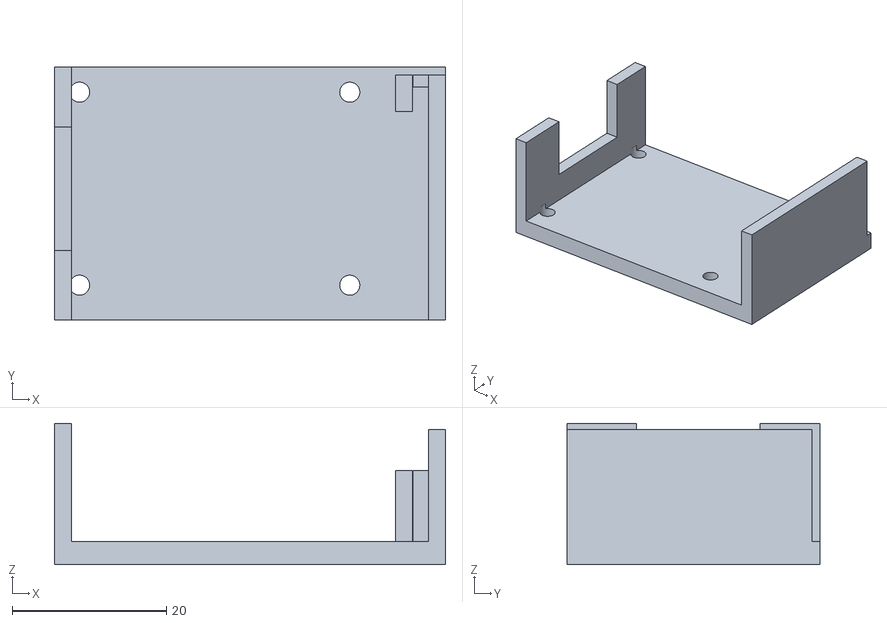
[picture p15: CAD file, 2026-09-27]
v3/stl/ph_adapter.stl
50.7 x 32.8 x 18.3

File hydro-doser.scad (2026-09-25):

// Hydro Doser -- a low unit that stands beside a hydroponic garden and doses
// straight into it: a water tank for top-offs, the two nutrient bottles,
// three peristaltic pumps. Firmware: firmware/hydro-doser/. Design notes,
// parts and the review that shaped this version: README.md,
// REVIEW-2026-09-23.md.
//
//   front
//   ╭──────────╮ ╭───╮       tank: a Cambro 6 qt bin on its dock. Its line
//   │  WATER   │ │Spr│       comes out of the column, in through a hole in
//   │          │ │   │       the lid, and sits on the bottom
//   │          │ │Thr│       column: two cans, one bottle each, front / back
//   ├──────────┴─┴───┤
//   │ [W]  [S]  ●○○ [T]      base: two trays bolted side by side. Pumps behind
//   └────────────────┘       removable covers; one sleeved bundle leaves the
//   345 wide x 225 deep x 315 tall     back, to the reservoir
//
// Coordinates: x across (0 = left), y depth (0 = front), z up. Printed parts
// are the shell colour, bought parts are drawn in their own colours. All
// printed parts print as they stand, no supports.
//
//   ./export.sh                                          # every print, into stl/
//   openscad -o mockup.stl hydro-doser.scad               # the whole unit, to look at
//   openscad -o x.stl -D 'part="column"' hydro-doser.scad

part    = "assembly";   // assembly | none | tray_dock | tray_col | plate | column | sleeve | cover | spout
bottles = "125";        // "125" = the small bottles in sleeves, "1L" = scaled up
fill    = 0.7;          // how full the tank is drawn, 0..1
$fn = 64;

// ------------------------------------------------------------ bought parts
// Cambro CamSquare 6 qt, 6SFSPP190: 8-3/8 x 8-3/8 x 7-1/4" (213 x 213 x 184),
// lid SFC6. The base taper, corner radius and lid are estimates. MEASURE.
bin_top   = 213;
bin_bot   = 195;
bin_h     = 184;
bin_r     = 14;
lid_w     = 219;
lid_above = 6;
lid_hole_d = 10;       // drilled in the lid for the tank line

// INTLLAB 12 V peristaltic pump, from its drawing: a 38 x 23 head, a
// 55 x 41 diamond flange with two 3.2 mm holes 48.5 apart on the horizontal
// axis, a 29 x 44 motor. Two nozzles stand 10 mm off the top of the head,
// 16 mm apart; the tube runs through the head and out of them.
pump_head_d  = 38;
pump_head_l  = 23;
pump_flange  = [55, 41];
pump_flange_t = 3;
pump_hole_sp = 48.5;   // the two mounting holes, centre to centre, on the flange's long axis
pump_hole_d  = 3.2;
pump_motor_d = 27;     // the drawing says 29 over the can's rim; retailers quote 26 for the can itself
pump_motor_l = 44;
nozzle_h     = 10;
nozzle_sp    = 16;     // the two nozzles, centre to centre, across the head's top
// The pump is rolled about its axis so the nozzles point up and sideways:
// upright, they'd run into the plate; at 90 degrees the upper mounting hole
// would fall inside the motor's U-slot. 42 degrees puts both holes on solid
// bulkhead and the upper nozzle's tube 4.6 mm under the plate. (The first
// dock tray was printed with the pump 2 mm higher: seat the pump at the
// bottom of its slot and roll it 43 degrees; that clears the plate by 2.8.)
pump_roll    = 42;

b125 = [54, 122];      // 125 mL bottle: [diameter, height with cap] (est.)
b1L  = [90, 230];      // a generic 1 L round
tube_od = 6.35;        // 1/4" silicone

// ------------------------------------------------------------------- shell
wall     = 3;
R        = 8;          // the unit's outer vertical corners
f_bot    = 1.5;        // fillet along the base's bottom edge (kept small: it prints as an overhang)
f_top    = 2;          // fillet along the plate's and the column floor's top edge
f_can    = 3;          // cove where each can meets the column floor
f_chase  = 2;          // cove where each chase and web wall meets it (2: stays clear of the pocket bore)
floor_t  = 4;
plate_t  = 4;
dock_w   = bin_top + 12;                   // 225: tank + 6 each side
cen_w    = 120;
D        = bin_top + 12;                   // 225
base_h   = 70;                             // tray + plate; the tank and column stand on this
tray_h   = base_h - plate_t;               // 66
can_h    = 245;                            // the column's cans, above its floor plate
W        = dock_w + cen_w;                 // 345
H        = base_h + can_h;                 // 315

x_cen    = dock_w;                         // the column tray starts here
tank_c   = [dock_w/2, D/2];

// Pumps: Water and Nutrient A in the dock, Nutrient B in the column tray with the
// electronics. Each lies along y, head to the front behind a removable
// cover, flange screwed from the front to a bulkhead, motor through a U-slot
// in it. Each is rolled so its two barbs point +x, into the room beside the
// head; the tubes loop back and pass through a slot in the bulkhead.
pump_x    = [46, 130, x_cen + 49];
pump_z    = floor_t + 28;                  // 2 mm lower than the first printed dock tray, for headroom over the nozzles
pump_y    = wall + 2;                      // head's front face
bulk_y    = pump_y + pump_head_l + 3;      // bulkhead's front face, where the flange sits
bulk_h    = tray_h - 0.5;                  // up to the plate: it carries the plate mid-span
barb_y    = pump_y + 8;                    // where the nozzles stand on the head
// A point (dx, dz) on the pump's cross-section, after the roll.
function rolled(dx, dz) = [dx*cos(pump_roll) + dz*sin(pump_roll), -dx*sin(pump_roll) + dz*cos(pump_roll)];
function nozzle(i)      = rolled((i == 0 ? -1 : 1) * nozzle_sp/2, pump_head_d/2 + nozzle_h);   // tip of nozzle i, (dx, dz) from the axis
function pump_hole(i)   = rolled((i == 0 ? -1 : 1) * pump_hole_sp/2, 0);                        // mounting hole i, (dx, dz) from the axis
function barb_tip(k)    = pump_x[k] + nozzle(1)[0];          // x of the outer nozzle's tip
function tube_slot_x(k) = pump_x[k] + 40;                    // where the tubes cross the bulkhead
opening   = 50;                            // front access opening (4 mm corners: the flange screws sit at their centres), behind a 68 x 62 cover
cover_t   = 2;
cover_screw = 29;                          // cover screws at (+-29, +-26), M3 into ribs inside the wall
cover_screw_z = 26;
cover_w   = 2*cover_screw + 10;           // 68: 5 mm around each screw, both ways
cover_h   = 2*cover_screw_z + 10;         // 62
crossbar_y = 165;                          // second wall across the dock, under the plate
pump_names = ["Water", "Nutrient A", "Nutrient B"];

// The column: two cans on a floor plate. Pockets take bottles up to ~92 mm.
can_od    = 102;
pocket_d  = 96;
can_c     = [[x_cen + cen_w/2, 56], [x_cen + cen_w/2, D - 56]];   // front: Nutrient A, back: Nutrient B; 5 mm in from the floor's edge so the coves land on flat plate
z_floor   = tray_h;                        // the column's floor plate sits on the tray
z_pocket  = z_floor + floor_t;             // 70, pocket floor
z_top     = z_pocket + can_h;              // 315
// Chases: a tube from the floor up, open at the top, one per line. Nutrient A's
// in the front can's front-left corner, Nutrient B's in the back can's
// back-right, and the tank line's in the left web wall. They stand as tall
// as the web walls, 12 mm below the can rims; each line simply comes out of
// the top of its chase.
chase_id  = 12;
chase_od  = 16;
chase_c   = [[x_cen + 19, 15], [x_cen + 12.5, D/2], [x_cen + cen_w - 19, D - 15]];   // Nutrient A, tank line, Nutrient B; each 1 mm into its can wall; the tank line's bore grazes the web wall by 0.5 (exactly tangent exports non-manifold)
chase_h   = floor_t + can_h - 12;
exit_z    = z_floor + chase_h;             // where the tank line leaves its chase
lid_hole  = [x_cen - 30, D/2];             // in the tank lid, under the tank line's exit
// Two walls join the cans into one stiff box section: each runs from the
// front can's centre line to the back can's, fusing into both can walls
// (the pockets cut away what falls inside them). The left one also carries
// the tank chase.
web_x     = [x_cen + 18, x_cen + cen_w - 21];
// The column's floor plate screws to the tray's posts where it is exposed:
// two free corners and the right side at the waist.
col_screws = [[x_cen + cen_w - 8, 8], [x_cen + 8, D - 8], [x_cen + cen_w - 8, D/2]];

// Seam between the trays: three M3 through-bolts, three tube holes (one in
// the front bay for Nutrient A's feed, two behind the bulkhead), a wire hole.
seam_bolts = [[16, 30], [D - 20, 30], [D/2, 56]];    // [y, z]
seam_tube  = [[20, 14], [110, 16], [130, 16]];   // the front one sits between the corner post and the bulkhead
seam_tube_d = 14;
seam_wire  = [150, 16, 10];
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

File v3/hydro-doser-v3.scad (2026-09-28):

// Hydro Doser v3, detailed to BRIEF.md.
//
// Frame: x right(0) -> left(202), y front(0) -> back(178), z up from the
// body's bottom edge. The base plate is below z = 0, the lid above H.
//
// Four printed pieces and a TPU foot:
//   body   the floor and the walls in one: the pump bulkhead, the two cups,
//          the front opening, the wall-board ribs, four snap-in feet under
//          the floor, a rim on top the lid caps over
//   lid    snaps over the body's rim, flush with it: a rounded edge, a
//          raised deck the bottles stand in, a tube hole beside each
//   plate  the black faceplate: carries the screen and the knob, screws
//          into the body at its corner-radius centres, flush, the seam a
//          rounded groove
//   knob, spout, foot
//
// Every edge is rounded. The bottles stand in the middle of the front; the
// three pumps lie across the back, heads forward, motors to the back wall,
// each rolled 42 degrees as in the first design so its flange screws sit on a
// 42 degree line; the DevKit rides on the faceplate behind the knob, the
// driver and the buck in slots on the side walls beside the cups; the jack
// and the GX12 sit low in the back wall between the motors, the grommet
// above the middle one; vents in the side walls beside the motors.

part = "all";
idx  = 0;
$fn  = 64;

// ------------------------------------------------------------------ brief
pump_head = [38, 23];  pump_flange = [55, 41, 3];  pump_motor = [27, 44];
flange_pitch = 48.5;  flange_hole = 3.2;
nozzle_off = 10;  nozzle_pitch = 16;  nozzle_y = 8;   // off the head's circumference; 8 in from the head's face
tube_od = 5;
esp  = [28.3, 51.5, 1.6, 8.5];             // the 30-pin DevKit V1: w (z), l (x), pcb, pins back; the pin rows 1.3 in from the long edges
esp_hole = [3, 2.3];                       // its four corner holes: dia, centre in from both edges (46.9 x 23.7 apart: measure yours)
phb  = [32, 42, 1.6, 8];                   // the pH board (PH-4502C type, its BNC removed): short side, long side, pcb, parts on its back
phb_hole = [3.1, 3.5];                     // its corner holes: dia, centre in from both edges (35 x 25 apart: measure yours)
pha  = [2.2, 3, 0, 5.5, 2.6];              // its adapter: leg thickness, bridge thickness, standoff height (0: the board sits on the bridge), standoff dia, M3 pilot through the bridge
enc_h = 14;                                 // the knob's encoder stands 14 off the plate's back once mounted (measured)
tds  = [32, 42, 1.6, 6];                   // the DFRobot Gravity TDS (or pH V2) signal board: short side, long side, pcb, parts on its back
tds_hole = [3.1, 3.5];                     // its four corner holes: dia, centre in from both edges (25 x 35 apart: measure yours)
tds_so   = [6, 25, 2.6];                  // standoffs: dia, height (lifts it over the screen's header and its Dupont plugs), pilot for an M3 self-tapper
esp_so   = [5.5, 5, 2.2];                    // standoffs: dia, height off the plate's back (clears the module and the USB), pilot for an M2.5 self-tapper
uln  = [32, 35, 15];  buck = [20, 45, 12]; // both turned to lie along y, between the motors
enc  = [31, 19, 1.6, 6.5, 11.5, 16, 6, 4.5, 9.5];   // pcb w, h, t; body, bushing top, shaft top above the pcb (the KY-040's 20 cut to 16: the knob's bore then reaches 1.2 short of its face); shaft dia, flat; shaft centre from the pcb's top edge
enc_nut = [10, 2.5];
oled = [27.3, 27.8, 1.6, 26.7, 19.3, 1.5, 21.7, 10.9];   // pcb w, h, t; glass w, h, t; active w, h
oled_glass_dz = -0.75;  oled_active_dz = 1.45;              // their centres, from the pcb's
jack_d = 11.5;  gx12_d = 12.2;  grommet_d = 16;
insert = [4, 5.5];  screw = [3.4, 6.7];    // M3 heat-set: hole dia, depth; M3 countersunk: clearance, head dia (+0.2)
bottle = [48, 122];   // measured 48 across; the height is still an estimate
rim = [4, 30];   // the garden reservoir's rim: thickness, drop

// ------------------------------------------------------------------- body
Bx      = 202;  By = 178;  wall = 3;
H       = 74;   R = 20;
lid_t   = 7;    lid_r = 4;                 // the lid: thick, its top edge rounded, flush with the walls
H_lid   = H + lid_t;
base_t  = 4;    base_ch = 1.5;             // the floor, below z = 0; a 45 chamfer under its edge: the one edge not rounded, so it prints from the bed
// The lid's snap: a rim rises from the walls' inner half with a ridge round its
// inside; the lid caps over it with a pocket underneath and a groove in the
// pocket's inner wall. Nothing hangs below the lid, so it prints flat.
// [rim thickness, rim height, clearance, ridge height, ridge proud, groove deep, ridge centre above the seam]  (cap: the reservoir's rim is rim)
cap     = [1.5, 4, 0.25, 1.4, 0.5, 0.7, 2];

// pumps: a row across the back, heads forward, each rolled 42 about its axis
pump_x  = [39, 101, 163];                  // pitch 62: a driver fits between two motors
pump_roll = 42;                            // as the first design: the nozzles lean left, the flange holes sit on a 42 line
head_y  = 99;                              // the head's front face
bulk_y  = head_y + pump_head[1] + pump_flange[2];   // 125: the bulkhead's front face, the flange against it
pump_z  = 28;                              // the axis
bulk_h  = 52;                              // the bulkhead's top: the tubes pass over it
motor_end = bulk_y + wall + pump_motor[1]; // 172
function rolled(dx, dz) = [dx*cos(pump_roll) + dz*sin(pump_roll), -dx*sin(pump_roll) + dz*cos(pump_roll)];   // (dx, dz) in the pump's section, rolled
function nozzle(s)   = rolled(s*nozzle_pitch/2, pump_head[0]/2 + nozzle_off);     // a nozzle's tip, (dx, dz) from the axis
function tube_start(s) = nozzle(s) + rolled(0, 5);                                  // where a tube's first bend can start: 5 beyond the tip, along the nozzle
function fhole(s)    = rolled(s*flange_pitch/2, 0);                                // a flange hole, (dx, dz) from the axis

// cups: two in the middle of the front; a Ø8 hole through the lid 16 mm out from each bottle for its tube, and a third at the rear, midway between them
cup_d = bottle[0] + 4;  cup_wall = 2;  hole_d = 8;   // the pocket: 2 mm round the bottle
cup_c = [[69, 62], [133, 62]];             // Nutrient A (right, fed by pump 0), Nutrient B (left, fed by pump 2)
hole_dx = [-(bottle[0]/2 + 16 + hole_d/2), bottle[0]/2 + 16 + hole_d/2];   // the hole's centre from the cup's: right cup's to the right, left cup's to the left

// boards. The DevKit stands on the faceplate's back behind the knob, its
// long side up, in two slotted rails; the driver and the buck stand in
// slotted ribs on the side walls beside the cups, dropped in from above.
wb      = [[3, 30, 35, 32], [Bx - 3, 30, 45, 20]];   // wall boards: [wall x, y0, length along y, height]: the ULN on the right wall, the buck on the left
wb_rib  = [7, 3.5, 1.8, 1.5, 4];           // rib depth off the wall, thickness (y), slot width, slot depth, pcb face off the wall
vents   = [[130, 40], [12, 5, 7], 2];      // in the side walls beside the motors: [y0, length], [z0, pitch, count], slot height

// feet: TPU, snapping into the base: disc dia, thickness, peg dia, lip dia, lip thickness
foot    = [18, 3, 7.8, 9.4, 1.4];
feet    = [[R, R], [Bx - R, R], [Bx - R, By - R], [R, By - R]];   // at the corners' radius centres

// ports: the back wall. The jack and the GX12 low, between the motors; the grommet above the middle one
port_z = 11;                                         // the jack, the outlets' grommet and the GX12 on one line, low: the grommet's hole clears the floor by 3
ports  = [[(pump_x[0] + pump_x[1])/2, port_z, jack_d], [pump_x[1], port_z, grommet_d], [(pump_x[1] + pump_x[2])/2, port_z, gx12_d], [pump_x[1], 58, hole_d]];   // x, z, dia: the jack, the pH probe's cable (its BNC plug passes through, a grommet round the cable) under the middle motor, the GX12, and the water tube's plain hole above the middle motor
out_barbs = [[pump_x[1] - 8, 48], [pump_x[1] + 5, 48], [pump_x[1] + 18, 48]];   // the three outlets, 13 apart, set right of centre so a driver still reaches the middle pump's upper screw (x 83, z 44): uxcell M6 bulkhead hose barbs (B0F5X3DXQ5) through the back wall, their nuts inside, over the middle motor's top
out_barb_d = 6.4;
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

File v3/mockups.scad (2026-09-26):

// Hydro Doser v3, massing mockups. Three layouts to choose between, drawn
// as blocks to the brief (BRIEF.md). No detailing: no fillets, fasteners,
// knurl or tube runs. Frame: x right(0) -> left, y front(0) -> back, z up
// from the tank's rim, which the box sits on.
//
//   opt 1  "Low":     pumps lying along the right side, box 74 tall,
//                     the bottles stand 50 above the lid.
//   opt 2  "Tall":    the same plan, box 110 tall, only the caps show.
//   opt 3  "Upright": pumps standing on the right, heads up, box 88 tall.

opt  = 1;
part = "all";     // all | shell | lid | panel | knob | pumps | boards | bottles | bin
$fn  = 48;

// ------------------------------------------------------------ the brief
bin_top = 213; bin_bot = 195; bin_h = 184; bin_r = 14; rim_t = 2;
pump_head = [38, 23]; pump_flange = [55, 41, 3]; pump_motor = [27, 44];
nozzle_off = 10; nozzle_pitch = 16; tube_od = 5;
esp = [55, 28, 12.5]; uln = [35, 32, 15]; buck = [45, 20, 12];
oled_win = [21.7, 10.9]; knob_d = 36; knob_h = 13; knob_sink = 2;
jack_d = 11.5; gx12_d = 12.2; grommet_d = 16;
bottle = [54, 122];

// ------------------------------------------------------------ the box
B = 219; wall = 3; floor_t = 4; lid_t = 5; R = 6;
H = opt == 1 ? 74 : opt == 2 ? 110 : 88;     // the walls
lip = [bin_top - 2*rim_t - 1, 8];           // a locator under the floor, inside the rim
ctl_z = opt == 2 ? 55 : H/2;                 // the controls' line on the front
upright = opt == 3;

// pumps: a row along the right side, behind the controls' zone
pump_y   = upright ? [60, 118, 176] : [60, 120, 180];   // upright: the flange is 55 long, so the pitch is 58
head_x   = wall + 4;                                   // lying: the head's face off the panel
bulk_x   = head_x + pump_head[1];                      // lying: the bulkhead the flanges sit on
pump_z   = 30;                                         // lying: the axis
shelf_z  = floor_t + pump_motor[1];                    // upright: the shelf the flanges sit on
pump_x   = wall + pump_head[0]/2 + 2;                  // upright: the row's x
panel_y  = [35, 205];                  // the side panel's span

// cups: two, along the left wall, behind the screen's zone
cup_d = 58; cup_wall = 2; cup_floor = 3;
cup_c = [[B - wall - cup_d/2 - cup_wall, B - wall - cup_d/2 - cup_wall], [B - wall - cup_d/2 - cup_wall, B - wall - cup_d/2 - cup_wall - 66]];

// boards: a strip between the pumps and the cups
strip_x = upright ? 60 : 88;
boards = [[[strip_x, 60, floor_t + 6], [esp[1], esp[0], esp[2]]], [[strip_x, 125, floor_t + 6], uln], [[strip_x, 168, floor_t + 6], buck]];

// ports: the back wall, over the boards
ports = [[105, jack_d], [127, gx12_d], [148, grommet_d]];
port_z = min(ctl_z, 40);

// controls: the front face, screen left, knob right
knob_x = 55; oled_x = B - 55;

// ------------------------------------------------------------ helpers
module rr(w, h, r) offset(r) offset(-r) square([w, h]);
module rrc(w, h, r) translate([-w/2, -h/2]) rr(w, h, r);

// ------------------------------------------------------------ pieces
module shell() color("#5a7a48") difference() {
  union() {
    difference() {
      linear_extrude(H) rr(B, B, R);
      translate([wall, wall, floor_t]) linear_extrude(H) rr(B - 2*wall, B - 2*wall, R - wall);
    }
    translate([(B - lip[0])/2, (B - lip[0])/2, -lip[1]]) difference() { linear_extrude(lip[1] + 0.01) rr(lip[0], lip[0], R); translate([2, 2, -1]) linear_extrude(lip[1] + 3) rr(lip[0] - 4, lip[0] - 4, R - 2); }
    if (!upright) translate([bulk_x, wall, floor_t - 0.01]) cube([wall, B - 2*wall, H - floor_t]);                 // the bulkhead
    if (upright) translate([wall, panel_y[0], shelf_z]) cube([pump_flange[1] + 4, panel_y[1] - panel_y[0], pump_flange[2]]);   // the shelf
    for (c = cup_c) translate([c[0], c[1], floor_t - 0.01]) cylinder(d = cup_d + 2*cup_wall, h = H - floor_t);   // the cups
    for (b = boards) translate(b[0] - [0, 0, 6]) cube([b[1][0], b[1][1], 6]);                                       // standoff blocks
  }
  translate([-1, panel_y[0], 8]) cube([wall + 2, panel_y[1] - panel_y[0], H - 12]);                                 // the side panel's opening
  for (c = cup_c) translate([c[0], c[1], floor_t + cup_floor]) cylinder(d = cup_d, h = H);                          // the pockets
  if (!upright) for (y = pump_y) translate([bulk_x - 1, y, pump_z]) rotate([0, 90, 0]) { cylinder(d = pump_motor[0] + 2, h = wall + 2); translate([-H, -(pump_motor[0] + 2)/2, 0]) cube([H, pump_motor[0] + 2, wall + 2]); }   // U-slots
  if (upright) for (y = pump_y) translate([pump_x, y, shelf_z - 1]) cylinder(d = pump_motor[0] + 2, h = pump_flange[2] + 2);
  for (p = ports) translate([p[0], B + 1, port_z]) rotate([90, 0, 0]) cylinder(d = p[1], h = wall + 2);            // the ports, back
  translate([oled_x, -1, ctl_z]) rotate([-90, 0, 0]) linear_extrude(wall + 2) rrc(oled_win[0] + 0.6, oled_win[1] + 0.6, 2);   // the window
  translate([knob_x, -1, ctl_z]) rotate([-90, 0, 0]) { cylinder(d = 7.5, h = wall + 2); cylinder(d = knob_d + 2, h = knob_sink + 1); }   // the bushing, the recess
}
module lid() color("#5a7a48") translate([0, 0, H]) difference() {
  linear_extrude(lid_t) rr(B, B, R);
  for (c = cup_c) translate([c[0], c[1], -1]) cylinder(d = cup_d + 0.4, h = lid_t + 2);
}
module panel() color("#3f5a33") translate([0, panel_y[0] + 0.3, 8.3]) cube([wall, panel_y[1] - panel_y[0] - 0.6, H - 12.6]);
module knob() color("#222") translate([knob_x, knob_sink, ctl_z]) rotate([90, 0, 0]) { cylinder(d = knob_d, h = knob_h - 2); translate([0, 0, knob_h - 2]) cylinder(d1 = knob_d, d2 = knob_d - 4, h = 2); }
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

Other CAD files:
v3/stl/body-print-1.3mf
stl/sleeve.stl
v3/stl/plate.stl
stl/spout.stl
v3/faceplate2/faceplate2.scad
stl/column.stl
stl/plate.stl
v3/outlet-block/outlet-block.scad
v3/stl/foot.stl
v3/stl/fuzz-modifier.stl
v3/stl/knob.stl
v3/stl/knob_cap.stl
v3/stl/lid.stl
v3/stl/lid_deck.stl
v3/stl/spout.stl

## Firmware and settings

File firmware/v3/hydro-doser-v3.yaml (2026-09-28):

# Hydro Doser v3 -- an ESP32 with a 0.96" OLED and a KY-040 knob on the
# faceplate, three 12 V peristaltic pumps through a ULN2003. Works without a
# phone: turn to choose, click to open, click to run; turn up past the top
# for Go back. Hold only runs a pump on Manual; on the home screen a 3 s hold
# turns the screen off, and a click turns it back on.
#
#   Hydrohomie  ->   Dose A        ->   Dose A, 25 ml
#   > Dose A         > 5 ml             12 s left
#     Dose B           10 ml            click to cancel
#     Dose C           25 ml
#     Dose ABC         50 ml
#     Settings         Manual          (hold the button: the pump runs while it is held)
#
#   Settings: PIN (set a 4-digit PIN with the knob; 0000 clears it), Autolock
#   (Off, 1 min, 5 min: with a PIN set, the screen locks after that long
#   without a touch and asks for the PIN), Reset (forget the network, the PIN
#   and the settings, and reboot into set-up).
#
# A is Nutrient A (pump 0), B is Nutrient B (pump 2), C is Water (pump 1),
# ABC runs A, then B, then C. A dose's time is ml / flow rate; the flow rates
# are numbers you can set from Home Assistant once the pumps are calibrated.
#
#   esphome run hydro-doser-v3.yaml --device /dev/cu.usbserial-110    # over USB
#   esphome run hydro-doser-v3.yaml --device hydro-doser-v3.local     # over the air after that
#
# Wiring (README.md): OLED SDA GPIO21, SCL GPIO22; knob's 5-pin plug on five
# neighbouring pins, CLK GPIO19, DT GPIO18, SW GPIO5, + GPIO17, GND GPIO16; ULN2003 IN1..IN3 GPIO25/26/27; Gravity TDS board's
# A on GPIO35, + on GPIO13, - on the GND pin beside 3V3 (GPIO32 was damaged 2026-09-28:
# GPIO32 and GPIO33 are left unused);
# pH board Po through a 10k/20k divider to GPIO34, V+ on 5 V (VIN); float
# switch GPIO14 to GND. The probes and the float come in through the GX12.

esphome:
  name: hydro-doser-v3
  friendly_name: Hydrohomie
  on_boot:
    - lambda: 'id(status).publish_state("idle");'
    - output.turn_off: knob_gnd  # the knob's ground ...
    - output.turn_on: knob_vcc   # ... and its 3.3 V
    - output.turn_on: tds_vcc    # the TDS board's 3.3 V, from GPIO13 (its ground on the GND pin beside 3V3)
  includes:
    - pumps.h       # pump_on / pumps_on, by the menu's numbering

esp32:
  board: esp32dev

logger:

# No credentials baked in. Out of the box the device offers two ways to
# join a network, both local: the Home Assistant app finds it over
# Bluetooth (Improv) and asks for the Wi-Fi details, or it raises an open
# "Hydrohomie" access point with a captive portal to type them into. Once
# on the network, Home Assistant discovers it and adds it with one click.
wifi:
  id: wifi_id
  ap:
    ssid: "Hydrohomie"
    ap_timeout: 1min          # the set-up modes come up a minute after a known network is not found
  on_connect:
    - component.update: oled
  on_disconnect:
    - component.update: oled

captive_portal:

improv_serial:

esp32_ble_server:

esp32_improv:
  authorizer: none
  on_provisioned:
    - component.update: oled

api:
  actions:
    - action: dose
      variables: { pump: string, ml: float }
      then:
        - lambda: "id(from_ha) = true;"
        - script.execute:
            id: dose
            which: !lambda 'return pump == "A" || pump == "a" ? 0 : pump == "B" || pump == "b" ? 1 : pump == "C" || pump == "c" ? 2 : 3;'
            ml: !lambda return ml;
    - action: cancel
      then:
        - script.execute: stop_all

ota:
  - platform: esphome

# ------------------------------------------------------------- the pumps
# Menu order A, B, C maps to the ULN2003's IN1 (Nutrient A), IN3 (Nutrient
# B), IN2 (Water): see the wiring table.
output:
  - platform: gpio
    id: out_a
    pin: GPIO25
  - platform: gpio
    id: out_b
    pin: GPIO27
  - platform: gpio
    id: out_c
    pin: GPIO26
  # The Gravity TDS board powered from GPIO13, so the firmware can switch it
  # off while pH reads: it draws a few mA.
  # The knob powered from the two pins beside its signals, so its 5-pin plug
  # goes on the header in one piece: it draws about 1 mA through its pull-ups.
  - platform: gpio
    id: knob_vcc
    pin: GPIO17
  - platform: gpio
    id: knob_gnd
    pin: GPIO16
  - platform: gpio
    id: tds_vcc
    pin: GPIO13                  # was GPIO32, damaged 2026-09-28; GPIO32 and GPIO33 now unused

switch:
  - platform: template
    id: sw_a
    name: "Pump A"
    icon: mdi:pump
    optimistic: true
    turn_on_action: { script.execute: { id: manual_on, which: 0 } }
    turn_off_action: { script.execute: stop_all }
  - platform: template
    id: sw_b
    name: "Pump B"
    icon: mdi:pump
    optimistic: true
    turn_on_action: { script.execute: { id: manual_on, which: 1 } }
    turn_off_action: { script.execute: stop_all }
  - platform: template
    id: sw_c
    name: "Pump C"
    icon: mdi:pump
    optimistic: true
    turn_on_action: { script.execute: { id: manual_on, which: 2 } }
    turn_off_action: { script.execute: stop_all }
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

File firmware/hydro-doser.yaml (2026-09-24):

# Hydro Doser -- four 12 V peristaltic pumps on an ESP32, via two ULN2003
# boards. Nutrient A and Nutrient B dose into a mix tank, a water pump fills it, and a
# transfer pump moves the mix into the reservoir. Wiring,
# calibration and use: README.md.
#
#   esphome run hydro-doser.yaml                                  # first flash, over USB
#   esphome run hydro-doser.yaml --device hydro-doser.local        # OTA after that
#
# All pumping goes through one queued script (run_pump), so only one pump
# ever runs at a time, and every run has a time limit. The firmware tracks how
# much is in the mix tank by counting (flow rate x run time). Nothing measures
# it, so keep the flow rates calibrated.

esphome:
  name: hydro-doser
  friendly_name: Hydro Doser
  includes:
    - doser.h        # pump indexes and names, the run-time limit

esp32:
  board: esp32dev

logger:

api:
  encryption:
    key: !secret api_key
  # For HA automations, e.g. a batch sized to what the garden used this week.
  actions:
    - action: dose
      variables: { pump: string, ml: float }
      then:
        - script.execute:
            id: run_pump
            p: !lambda return pump_index(pump);
            ml: !lambda return ml;
            seconds: 0
            account: true
    - action: make_batch
      variables: { liters: float, nutrients: bool }
      then:
        - script.execute:
            id: make_batch
            liters: !lambda return liters;
            nutrients: !lambda return nutrients;
    - action: transfer
      variables: { liters: float }
      then:
        - script.execute:
            id: run_pump
            p: 3
            ml: !lambda "return liters > 0 ? liters * 1000.0f : 1e9f;"
            seconds: 0
            account: true

ota:
  - platform: esphome
    password: !secret ota_password

wifi:
  networks:
    - ssid: !secret wifi_ssid
      password: !secret wifi_password
    - ssid: !secret wifi_ssid_main
      password: !secret wifi_password
  ap:
    ssid: "Hydro Doser Setup"
    password: !secret ap_password

captive_portal:

# --------------------------------------------------------------------- pumps
# Each pump hangs off two ULN2003 channels in parallel: one GPIO drives both
# INs, and the pump's - lead goes to both OUTs. That's 1 A of sink for a pump
# that draws a few hundred mA. Pump + goes to the board's + pin (12 V). The
# ULN2003's own diodes catch the motor's flyback.
#   board A: IN1+IN2 Nutrient A, IN3+IN4 Nutrient B
#   board B: IN1+IN2 Water,  IN3+IN4 Transfer
output:
  - { platform: gpio, id: out_sprout,   pin: GPIO25 }
  - { platform: gpio, id: out_thrive,   pin: GPIO26 }
  - { platform: gpio, id: out_water,    pin: GPIO27 }
  - { platform: gpio, id: out_transfer, pin: GPIO32 }

globals:
  # Tracked across reboots: what's in the mix tank, and what's left the
  # nutrient bottles since each was last refilled.
  - { id: mix_ml,      type: float, restore_value: true, initial_value: '0' }
  - { id: sprout_used, type: float, restore_value: true, initial_value: '0' }
  - { id: thrive_used, type: float, restore_value: true, initial_value: '0' }
  # The run in progress. run_pump_idx is -1 when no pump is on.
  - { id: run_pump_idx, type: int,      initial_value: '-1' }
  - { id: run_start,    type: uint32_t, initial_value: '0' }
  - { id: run_ms,       type: uint32_t, initial_value: '0' }
  - { id: run_account,  type: bool,     initial_value: 'true' }
  - { id: batch_ok,     type: bool,     initial_value: 'false' }
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

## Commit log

2026-09-24 Hydro Doser: printable model, checks, renders and the on-hold firmware
    [column.stl, cover.stl, hydro-doser.scad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]
2026-09-24 One ULN2003, three print colours, shopping list with two sources per part
    Claude-Session: https://claude.ai/code/session_017SkXnBJbjB2U3goQfffMsB
    [hydro-doser.scad]
2026-09-25 Two-colour column, panel adapter plate with tactile switches, 68 x 62 covers, GX12-6
    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
    [button_cap.stl, column_floor.stl, column_towers.stl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]
2026-09-26 v3: clean-sheet enclosure, faceplate with screen, knob and ESP32, menu firmware
    The v3 model, its brief, checks, mockups and STLs under v3/; the ESPHome
    firmware (menu only, pumps next) under firmware/v3/. v1 stays at the root.
    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
    [body.stl, foot.stl, fuzz-modifier.stl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]
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2026-09-26 v3 firmware: opening a dose no longer runs its first quantity
    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
    [hydro-doser-v3.yaml]
2026-09-26 v3 firmware: row text raised in its highlight; cancel drawn as a button
    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
2026-09-26 v3: the screen as close to the plate's edge as the knob
    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
    [body.stl, fuzz-modifier.stl, hydro-doser-v3.scad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]
2026-09-26 v3 firmware: the owner's networks from secrets, the set-up flow for everyone else
    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
2026-09-26 v3 firmware: Settings with PIN, Autolock and Reset
    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
    [hydro-doser-v3.yaml]
2026-09-26 v3: the knob brick red
    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
    [hydro-doser-v3.scad]
2026-09-26 v3: the knob burnt orange
    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
    [hydro-doser-v3.scad]
2026-09-26 v3: the knob a darker burnt orange
    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
    [hydro-doser-v3.scad]
2026-09-26 v3: the knob half as thick, the encoder's shaft cut to 13.5
    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
    [hydro-doser-v3.scad, knob.stl]
2026-09-26 v3: black second colours, the knob's cap, the lid's deck, the body's cups
    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
    [body.stl, body_cups.stl, hydro-doser-v3.scad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]
2026-09-26 v3: the cups back to olive; the third tube hole at the lid's rear edge
    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
    [body.stl, body_cups.stl, hydro-doser-v3.scad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]
2026-09-26 v3: the tube-route check follows the hole to the rear
    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
2026-09-26 v3 render: the tubes, the wiring and the heat-set inserts in the explosion
    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
2026-09-26 v3: the water tube's hole low in the back wall, no third hole in the lid; the explosion without wiring, black screws
    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
    [body.stl, hydro-doser-v3.scad, lid.stl]
2026-09-26 v3 render: a width option; the encoder takes the frames' size
    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
2026-09-26 v3: the knurled ring brown-red; the menu on the screen in the render
    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
    [hydro-doser-v3.scad]
2026-09-26 v3: the Rise Gardens bottles modelled, with caps and labels; the render's blacks matte
    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
    [hydro-doser-v3.scad]
2026-09-26 v3: the knob 9.5 thick, its D bore to 1.2 short of the face, the shaft cut to 16
    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
    [hydro-doser-v3.scad, knob.stl, knob_cap.stl]
2026-09-26 v3: the deck and the faceplate inset 12.8 from every edge, the plate's radius on the deck
    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
    [body.stl, fuzz-modifier.stl, hydro-doser-v3.scad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]
2026-09-26 v3: the DevKit V1 on four standoffs left of the screen, the band notched behind it; 12 between the knob and the screen
    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
    [body.stl, hydro-doser-v3.scad, plate.stl]
2026-09-26 v3: the DevKit lying along the plate, the screen and the knob moved right to make room
    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
    [body.stl, hydro-doser-v3.scad, plate.stl]
2026-09-26 v3: a mount for the Gravity TDS board right of the knob, on four 10 mm standoffs
    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
    [body.stl, hydro-doser-v3.scad, plate.stl]
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2026-09-26 v3: the screen dead centre, the knob midway to the right edge, the TDS board behind the screen
    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
    [body.stl, hydro-doser-v3.scad, plate.stl]
2026-09-26 v3: the screen drops into a pocket, 0.2 wider, no slots or ledge
    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
    [hydro-doser-v3.scad, plate.stl]
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2026-09-26 v3 firmware: pH through a divider, two-point calibrated; a fail-safe float switch; the GX12's six pins
    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
    [hydro-doser-v3.yaml]
2026-09-26 v3: a printed adapter that hangs the pH board on the encoder's ribs
    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
    [hydro-doser-v3.scad, ph_adapter.stl]
2026-09-26 v3: the outlets' grommet and the water hole swapped; the jack, grommet and GX12 on one line, low
    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
    [body.stl, hydro-doser-v3.scad]
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2026-09-27 v3: one rib by the encoder, its pins out sideways and 14 tall; the pH adapter clamps that rib and bridges over the encoder
    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
    [hydro-doser-v3.scad, ph_adapter.stl, plate.stl]
2026-09-27 v3: the pH adapter gets a wall along its bed edge
    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
    [hydro-doser-v3.scad, ph_adapter.stl]
2026-09-27 v3: the pH adapter's far end on a full-height leg to the plate, windowed for the harness
    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
    [hydro-doser-v3.scad, ph_adapter.stl]
2026-09-27 v3: the pH adapter without standoffs, plain holes; printed flat side down
    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
    [hydro-doser-v3.scad, ph_adapter.stl]
2026-09-27 v3: faceplate 2, every board on the plate, no adapters
    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
    [faceplate2.scad, faceplate2.stl]
2026-09-28 v3: an outlet block for the back's outlet hole, three push-on barbs
    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
    [outlet-block.scad, outlet-block.stl]
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2026-09-28 v3 faceplate 2: the screen turned header-down, yellow on top
    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
    [faceplate2.scad, faceplate2.stl]
2026-09-28 v3 faceplate 2: no rib by the encoder
    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
    [faceplate2.scad, faceplate2.stl]
2026-09-28 v3 faceplate 2: no knob recess, the face flat
    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
    [faceplate2.scad, faceplate2.stl]
2026-09-28 v3 faceplate 2: a groove for the screen's solder points
    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
    [faceplate2.scad, faceplate2.stl]
2026-09-28 v3 faceplate 2: the screen header-up, the solder groove above the glass
    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
    [faceplate2.scad, faceplate2.stl]
2026-09-28 v3 faceplate 2: bezel alignment holes round the knob
    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
    [faceplate2.scad, faceplate2.stl]
2026-09-28 v3 back wall: pH cable hole, three outlet barb holes; pH board off faceplate 2 and the GX12
    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
    [body-print-1.3mf, faceplate2.scad, faceplate2.stl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]
2026-09-28 v3: re-exported pieces with the barb holes
    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
    [body.stl]
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2026-09-28 v3 firmware: TDS supply on GPIO13 (GPIO32 damaged)
    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
    [hydro-doser-v3.yaml]
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
